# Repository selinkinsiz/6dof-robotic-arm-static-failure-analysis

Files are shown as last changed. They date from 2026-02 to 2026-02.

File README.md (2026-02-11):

# 6dof-robotic-arm-static-failure-analysis
Static structural analysis of a 6-DOF robotic arm using SolidWorks

## Project Overview
This project involves the mechanical design and static structural analysis of a 6-degree-of-freedom (6-DOF) robotic arm using SolidWorks Simulation. The objective was to evaluate structural integrity under applied loading conditions.

## Analysis Setup
- Material properties defined within SolidWorks
- Fixed support boundary condition applied at the base
- External load equivalent to 50 kg (~490 N) applied at the end-effector
- Finite Element Analysis (FEA) performed
- Von Mises stress criterion used for failure evaluation

## Evaluation Parameters
- Maximum von Mises stress distribution
- Maximum displacement and deformation
- Factor of Safety (FOS)
- Stress concentration regions

## Results
The analysis identified critical stress regions near joint connections and load-bearing sections. 
Maximum displacement was evaluated to ensure functional rigidity. 
Factor of Safety was calculated to verify structural reliability under the applied load.

## Tools Used
- SolidWorks
- SolidWorks Simulation (FEA Module)

## Repository Structure
- cad/ → CAD assembly and part files
- analysis/ → Simulation-related files and animation
- images/ → Stress, displacement, and FOS visualizations
- report/ → Detailed technical report
- presentation/ → Project presentation

## Conclusion
This project provided hands-on experience in finite element analysis, mechanical design validation, load application, and structural optimization for robotic systems.

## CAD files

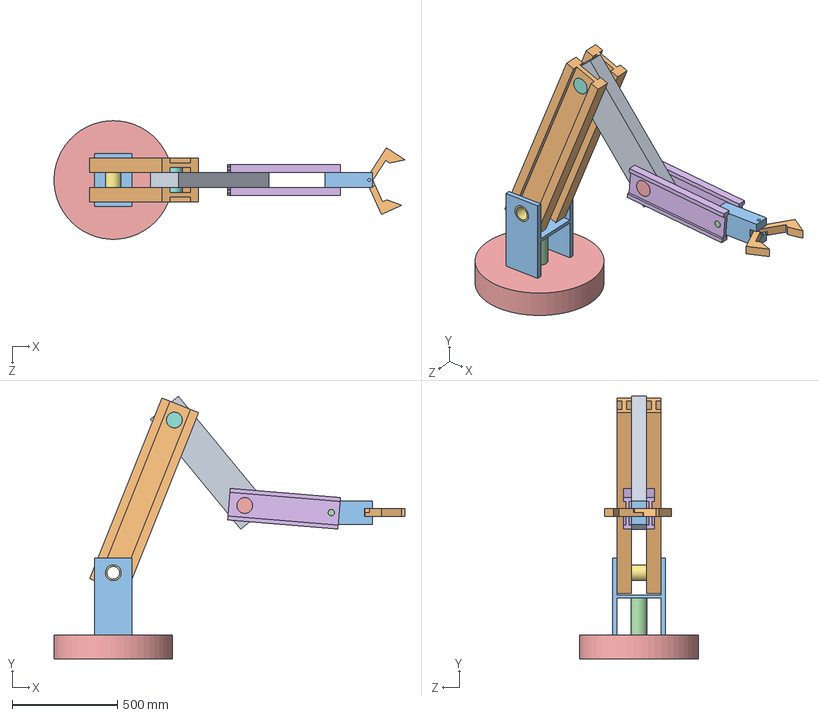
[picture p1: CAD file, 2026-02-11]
SOLIDWORKS Design Files/MECA_321_Project.SLDASM
1663.9 x 1244.5 x 562.5 mm
Base
Arm_1 x 2
Arm_2
Pin_1.2
Pin_Hole
Arm_3 x 2
Pin_2.3
Pin_3.4
Arm_4
Gripper x 2
Pin_Gripper

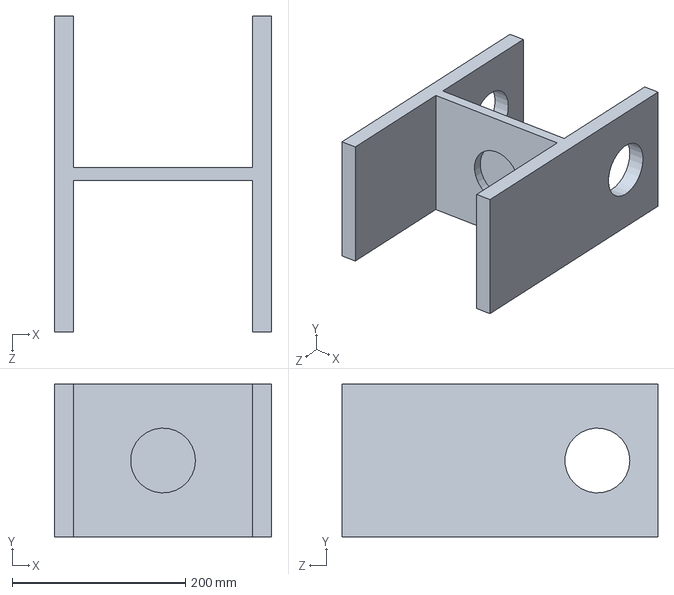
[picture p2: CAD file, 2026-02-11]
SOLIDWORKS Design Files/Body.SLDPRT
251.2 x 176.2 x 365.1 mm

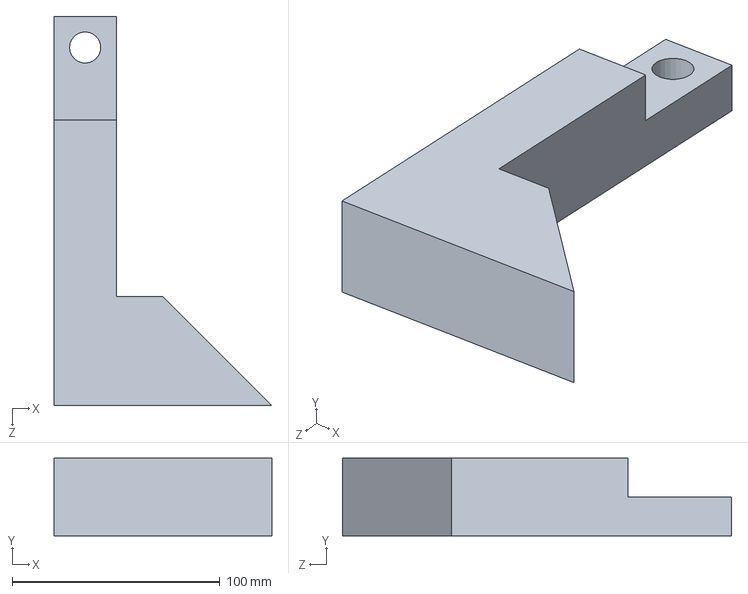
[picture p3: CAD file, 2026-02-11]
SOLIDWORKS Design Files/Gripper.SLDPRT
105.0 x 37.5 x 187.5 mm

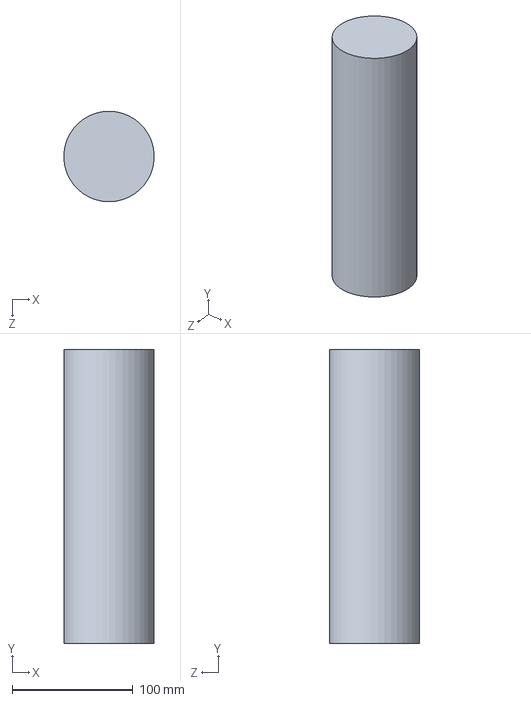
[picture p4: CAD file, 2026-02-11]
SOLIDWORKS Design Files/Cylinder.SLDPRT
74.8 x 243.8 x 75.0 mm

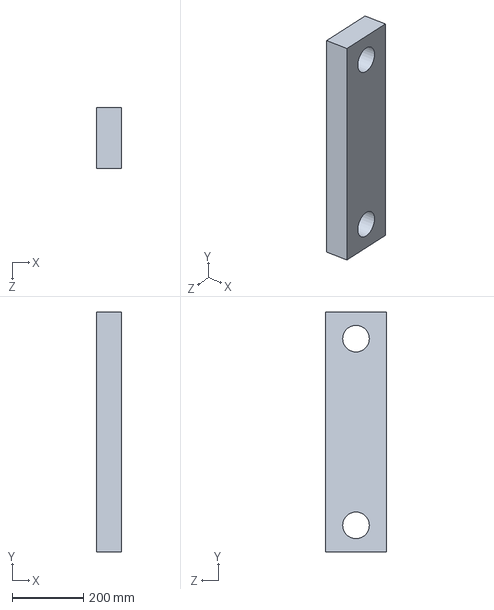
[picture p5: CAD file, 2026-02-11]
SOLIDWORKS Design Files/Arm_2.SLDPRT
71.2 x 674.7 x 172.5 mm

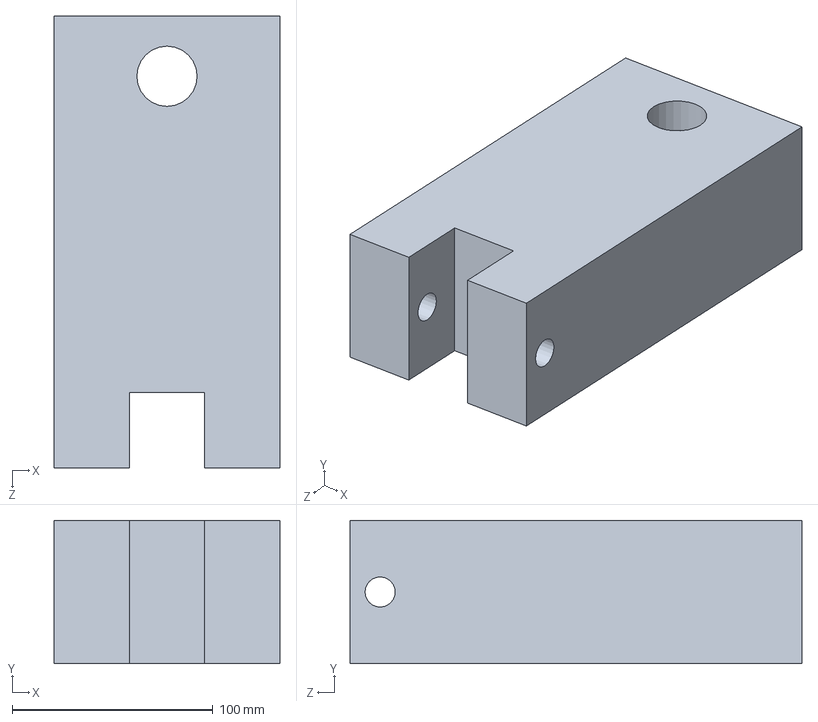
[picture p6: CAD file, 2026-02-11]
SOLIDWORKS Design Files/Arm_4.SLDPRT
112.5 x 71.2 x 225.0 mm

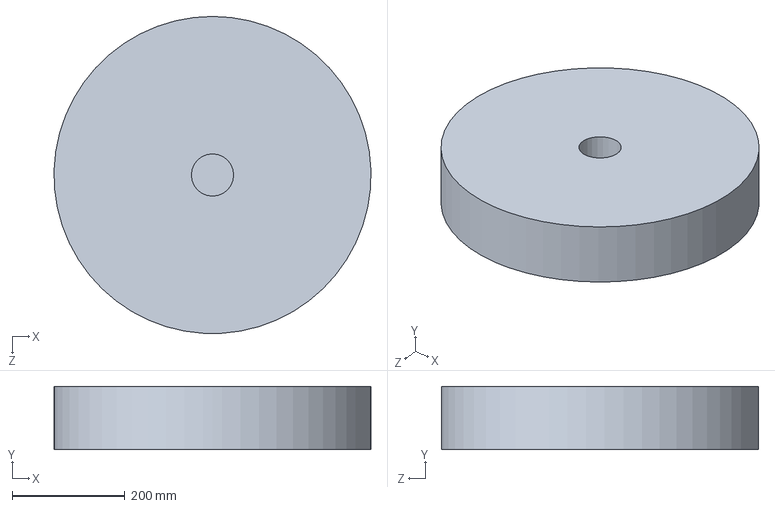
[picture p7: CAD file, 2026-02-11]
SOLIDWORKS Design Files/Base.SLDPRT
562.3 x 112.5 x 562.5 mm

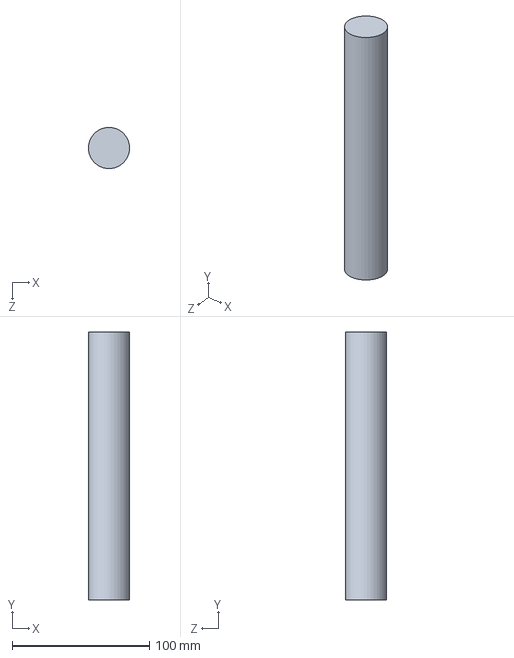
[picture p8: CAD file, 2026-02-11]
SOLIDWORKS Design Files/40_260pim.SLDPRT
30.0 x 195.0 x 30.0 mm

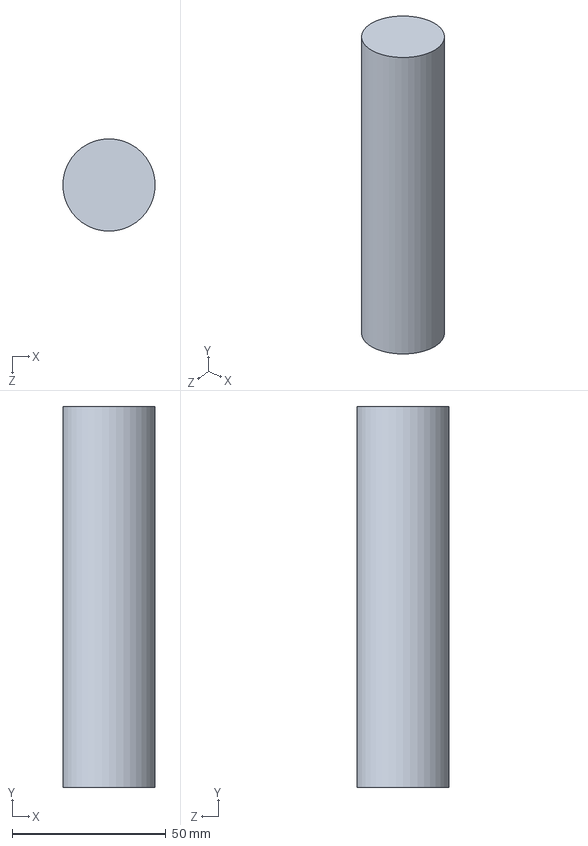
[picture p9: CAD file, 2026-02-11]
SOLIDWORKS Design Files/Pin_3.4.SLDPRT
30.0 x 123.7 x 30.0 mm

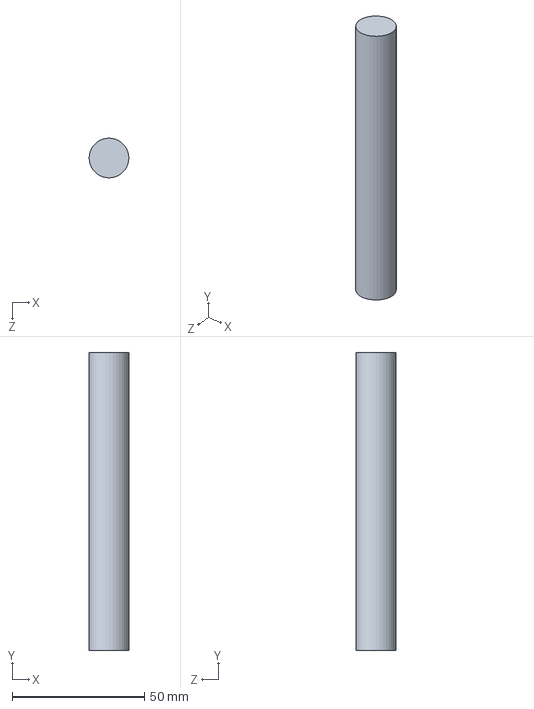
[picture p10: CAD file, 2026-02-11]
SOLIDWORKS Design Files/Pin_Gripper.SLDPRT
15.0 x 112.5 x 15.0 mm

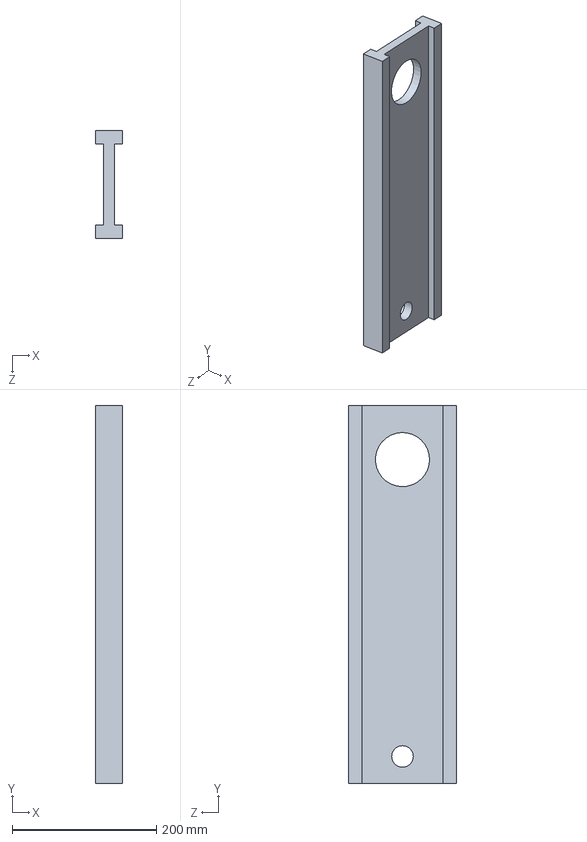
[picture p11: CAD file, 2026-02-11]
SOLIDWORKS Design Files/Arm_3.SLDPRT
37.5 x 524.3 x 150.0 mm

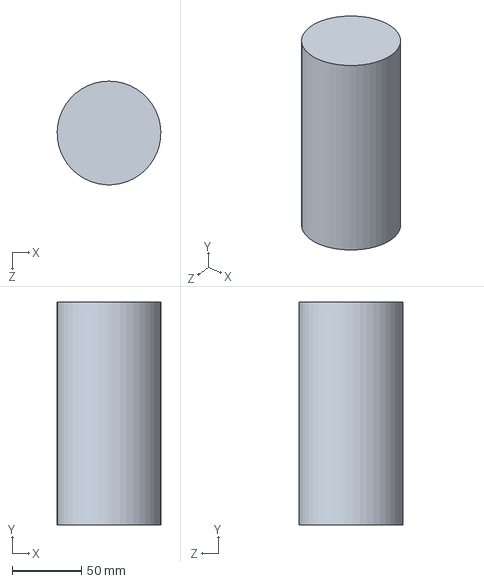
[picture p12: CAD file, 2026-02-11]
SOLIDWORKS Design Files/Pin_1.2.SLDPRT
75.0 x 161.2 x 75.0 mm

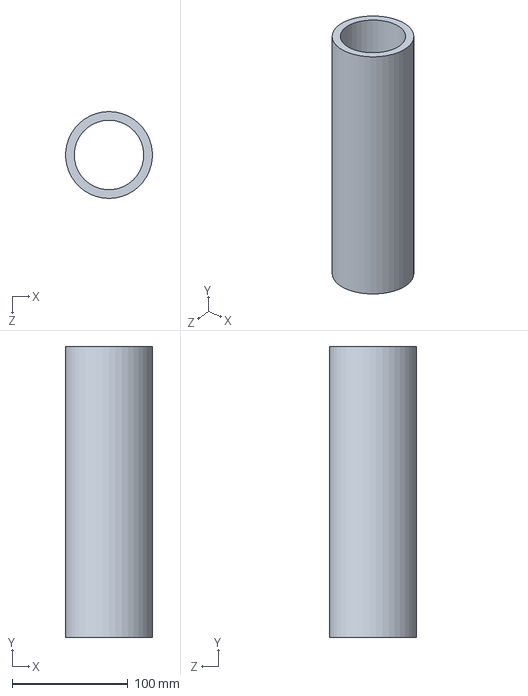
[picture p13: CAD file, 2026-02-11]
SOLIDWORKS Design Files/Pin_Hole.SLDPRT
74.8 x 251.2 x 75.0 mm

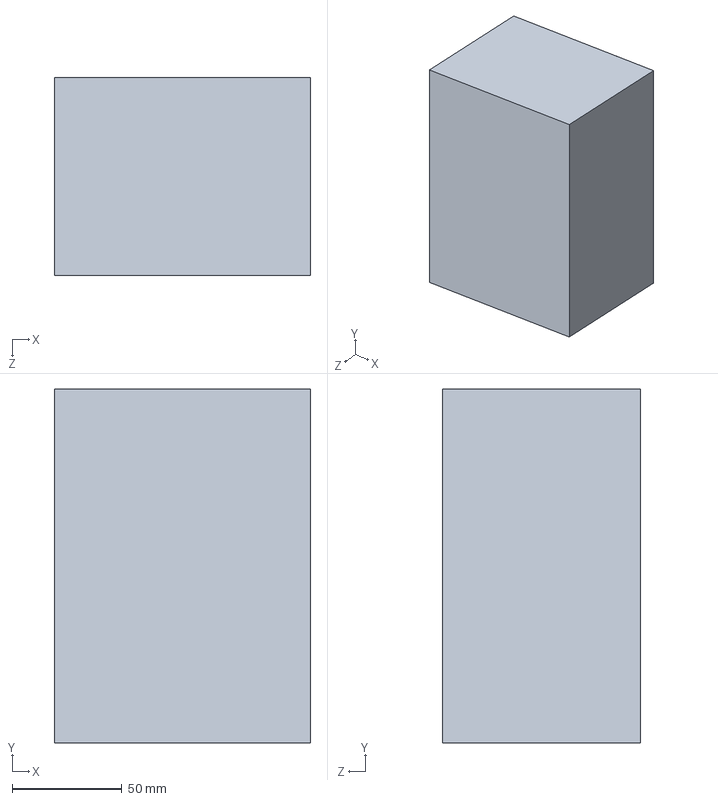
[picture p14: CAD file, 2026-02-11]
SOLIDWORKS Design Files/cube.SLDPRT
116.7 x 161.2 x 90.0 mm

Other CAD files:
SOLIDWORKS Design Files/Pin_2.3.SLDPRT
SOLIDWORKS Design Files/stick.SLDPRT
SOLIDWORKS Design Files/Arm_1.SLDPRT

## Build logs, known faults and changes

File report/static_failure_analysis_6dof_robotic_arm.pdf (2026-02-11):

Selin Rabia Kinsiz 122207037

Serra Lal Tosun 123207041

Yağız Gelen 122207048

Emir Eren 122207095

A Report Submitted to the

Mechatronics Engineering Department of

In MECA 321 Mechanics of Material

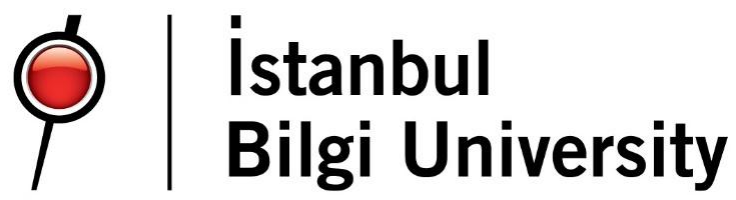
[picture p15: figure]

Table of Contents

### 1. Design Requirements and Assumptions

### 1.1 Design Requirements

- Payload Capacity: The robotic arm is designed to lift a payload of 50 kg located 2
meters | away | from | its | base.
- Safety Standards: A minimum Factor of Safety (FOS) of 2 is targeted for all structural
components | to | prevent | static | failure.
- Structural Geometry: Industrial standard profiles (I beams) are utilized for the arm links to optimize the strength to weight ratio and ensure manufacturability.
- Component Assembly: The design incorporates a combination of solid and hollow cylindrical pins of varying dimensions for joint assemblies, selected to optimize weight and structural integration.

### 1.2 Assumptions

- Material Properties: The material (HDPE) is assumed to be isotropic and homogeneous. Constant properties (Elastic Modulus: 1.07 GPa, Yield Strength: 22 MPa) are applied throughout the volume.
- Geometric Profile: The arm links are modeled using standard industrial I beam profiles to optimize the strength to weight ratio, in accordance with the design requirements.
- Static Loading: The payload of 50 kg is applied as a static force. Dynamic effects such as angular acceleration, inertia forces during movement, and vibrations are not included.

Boundary Conditions: The base of the robot is fixed at the bottom face, assuming a perfectly rigid installation surface with zero degrees of freedom.

Linear Elasticity: The analysis assumes linear elastic material behavior. Nonlinear effects such as plasticity, time dependent deformation, or large displacement non linearities are neglected for this static study.

Thermal Conditions: The analysis is conducted at standard room temperature (approx. 20-25°C). Thermal expansion or softening of the HDPE material is not considered.

### 2. Conceptual Design

The proposed robotic arm is designed as a multi segment serial manipulator. Specifically engineered to lift a 50 kg payload at a maximum reach of 2 meters. The design balances structural strength and weight efficiency. It utilizes a step-down linkage strategy to minimize the moment of inertia and stress on the base joints.

### 2.1 Configuration and Degrees of Freedom (DOF)

The robotic arm consists of a series of rigid links connected by rotational joints. The configuration is arranged to provide the necessary workspace and control for the lifting task. The design features the following primary segments:

- Base & Body: Provides a rigid foundation and vertical difference.
- Serial Linkages: The arm utilizes a successive arrangement of links that decrease in size and mass from the shoulder to the end effector. This configuration allows for a fully extended "worst case" reach while maintaining stability.

### 2.2 Structural Optimization and Material

To satisfy the design requirements, the arm links are designed with standard I beam profiles

- Mass Distribution Strategy: As seen in the design data, the mass of the links is progressively reduced (from approx. 13.5 kg for the first link to 1.5 kg for the final link). This " decreasing" strategy significantly reduces the bending moment applied to the root joints and optimizes the center of mass location.
- Material: High Density Polyethylene (HDPE) is selected as the primary structural material (E = 1.07 GPa), offering a high strength to weight ratio crucial for this multi-link setup.

### 2.3 Assembly and Joint Design

The mechanical integration of the segments is achieved using a specifically calculated pin system.

- Pin Selection: The assembly incorporates a hybrid approach using both solid pins and a hollow pin.
- Function: Hollow pins are utilized in lower stress joints to further reduce the total weight, while solid pins are kept for critical load bearing joints, ensuring the design meets the safety factor requirements.

### 3. CAD Design (SolidWorks)

The complete 3D geometric model of the robotic arm was developed using SolidWorks software, sticking to the project requirements for solid modeling and parametric design.

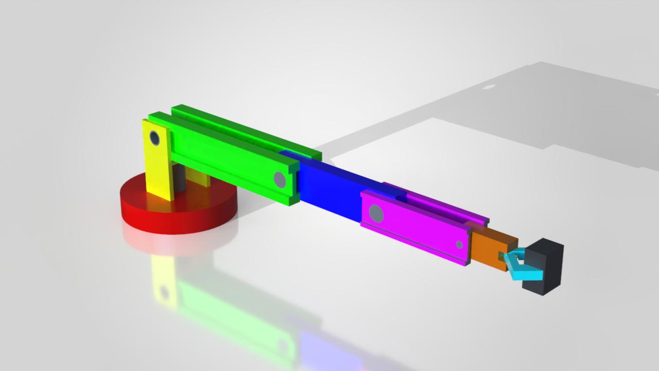
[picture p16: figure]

### 3.1 Modeling Methodology

The design process began with the creation of individual components representing the base, vertical body, and the four arm segments.

- Part Creation: Each link was modeled by sketching the cross-sectional profiles and using extrusion features to generate the 3D geometry. As specified in the conceptual design, the links were shaped to resemble I beam profiles to optimize rigidity.
- Pin & Connection Modeling: Specific connection pins were modeled as separate components. A combination of solid and hollow cylindrical pins was created to accurately represent the physical assembly and mass distribution.

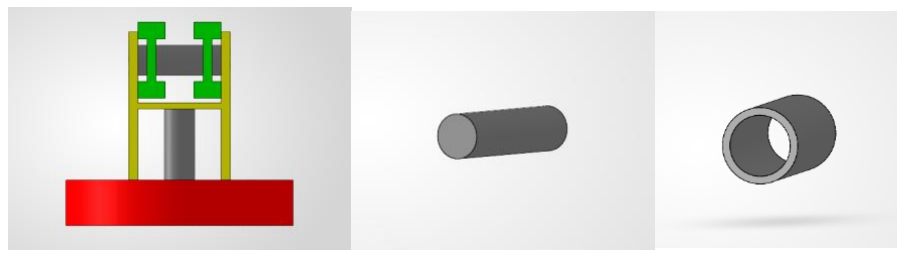
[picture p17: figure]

### 3.2 Assembly and Constraints

The individual parts were integrated into a final assembly file (.SLDASM) using standard mating conditions.

- Joint Constraints: Centered and aligned mates were applied between the link holes and the connecting pins to define the proper alignment of the revolute joints.
- Configuration: For the design validation, the assembly was constrained in a fully extended horizontal position. This configuration represents the "worst case" scenario where the moment arm is longest (2 meters), ensuring that following analyses cover the most critical loading condition.

### 3.3 Material Assignment and Mass Properties

To ensure accurate physical simulation, the material properties of High-Density Polyethylene (HDPE) were assigned to all structural components within the SolidWorks environment.

- Mass Calculation: Using the "Mass Properties" tool, the weight of each component and the center of gravity (COG) of the entire assembly were calculated. The payload was modeled by main the mass properties of the end effector load to 50 kg, simulating the target lifting capacity.

### 4. Material and Cross-Section Selection

This section outlines the reason behind the selection of materials and geometric profiles used in the robotic arm. The choices were driven by the design objectives of minimizing weight while ensuring sufficient stiffness to support the 50 kg payload.

Table 1: Material properties assigned to the robotic arm components

Component | Material | E (GPa) | Yield Strength (MPa) | Density (kg/m³)
Base | High-Density Polyethylene | 1.07 | 22 | 960
Body | High-Density Polyethylene | 1.07 | 22 | 960
Arm_1 | High-Density Polyethylene | 1.07 | 22 | 960
Arm_2 | High-Density Polyethylene | 1.07 | 22 | 960
Arm_3 | High-Density Polyethylene | 1.07 | 22 | 960
Arm_4 | High-Density Polyethylene | 1.07 | 22 | 960
Gripper | High-Density Polyethylene | 1.07 | 22 | 960

Cylinder | High-Density Polyethylene | 1.07 | 22 | 960
Pim_Hole | High-Density Polyethylene | 1.07 | 22 | 960
Pim_1.2 | High-Density Polyethylene | 1.07 | 22 | 960
Pim_2.3 | High-Density Polyethylene | 1.07 | 22 | 960
Pim_3.4 | High-Density Polyethylene | 1.07 | 22 | 960
Pim_Gripper | High-Density Polyethylene | 1.07 | 22 | 960

### 4.1 Cross-Section Selection: Industrial I-Beams

In accordance with the design requirements to use industrial standard profiles, the arm links are modeled with I beam cross-sections.

- Geometric Advantage: The I beam geometry places most of the material mass (flanges) away from the neutral axis. This significantly increases the Area Moment of Inertia (I) relative to the cross-sectional area.
- Bending Resistance: Since the primary failure mode for the horizontal arm is bending due to the vertical payload, the high moment of inertia provided by the I beam profile offers higher resistance to deflection compared to solid rectangular bars of equal weight.

### 5. Structural Analysis for Static Failure

In this section, the structural behavior of the robotic arm under static loading is evaluated. By applying the design loads to the HDPE structure, both analytical and numerical methods were used to calculate maximum stress and deflection. The results presented below demonstrate the comparison between theoretical expectations and simulation outputs, ensuring the design meets the minimum Factor of Safety criteria.

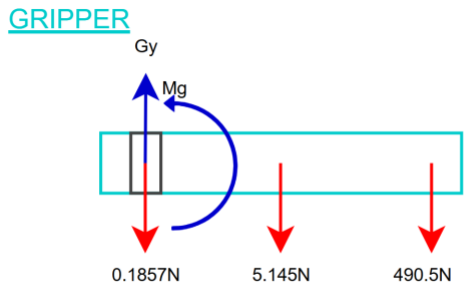
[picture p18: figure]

### 5.1 FBD

Gripper

CW = −

CCW = +

∑Fy = 0 , Gy = +495.837

∑MG = 0, MG = 0.46 + 72.834

MG = +73.294Nm

Arm4

A4y= +511.960N

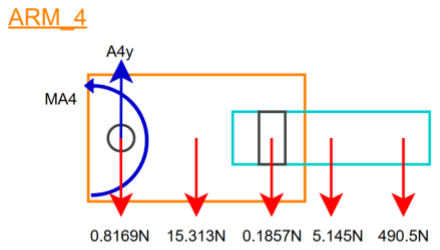
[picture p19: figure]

MA4= (15.313 × 0.07852) + (5.145 × 0.151792) + (490 × 0.328119) + (0.1857 × 0.18)

MA4= 1.202 + 0.781 + 161.124 + 0.033

MA4= 163.140Nm

Arm3

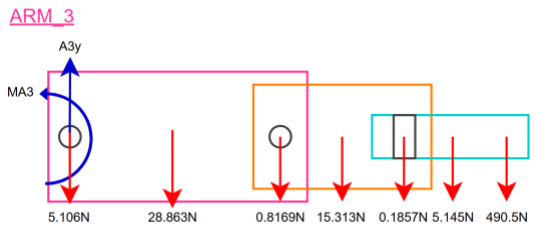
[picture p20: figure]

A3y= 510.958 + 28.853

A3y= 545.9396N

MA3= (0.19365 × 28.863) + (0.49035 × 15.313) + (0.68122 × 5.145) + (0.74032 ×
490.5) + (0.1857 × 0.59183) + (0.8169 × 0.41183)

MA3= 5.589 + 7.509 + 3.505 + 363.127 + 0.1099 + 0.3364

MA3= 380.176Nm

Arm2

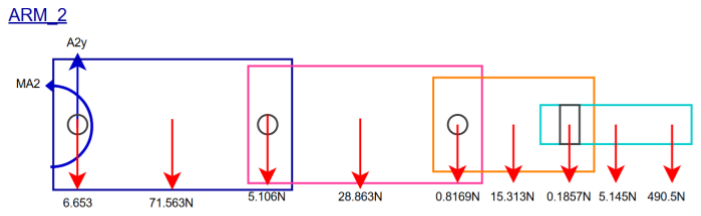
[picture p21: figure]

A2y= 539.821 + 71.563

A2y= 624.1456N

MA2= 18.774 + 20.733 + 15.543 + 6.204 + 620.483 + 0.207 + 0.765 + 2.6789

MA2= 685.3879Nm

Arm1

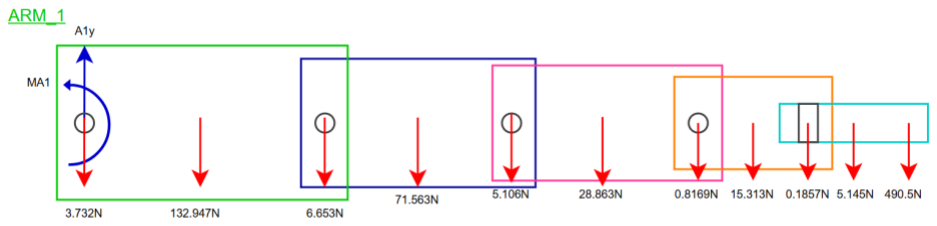
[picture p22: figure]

A1y= 611.384 + 132.947

A1y= 760.8244N

MA1= (0.39385 × 132.947) + (1.0234 × 71.563) + (1.49833 × 28,863) + (1.79503 × 15.313) + (1.9859 × 5.145) + (2.045 × 490.5) + (0.1857 × 1.89651) + (0.8169 × 1.71631) + (5.1058 × 1.30468) + (6.653 × 0.78)

MA1= 52.361 + 74.593 + 43.246 + 27.487 + 10.217 + 1003.073 + 0.33522 + 1.4022 + 6.6614 + 5.18934

MA1= 1224.582Nm

Body

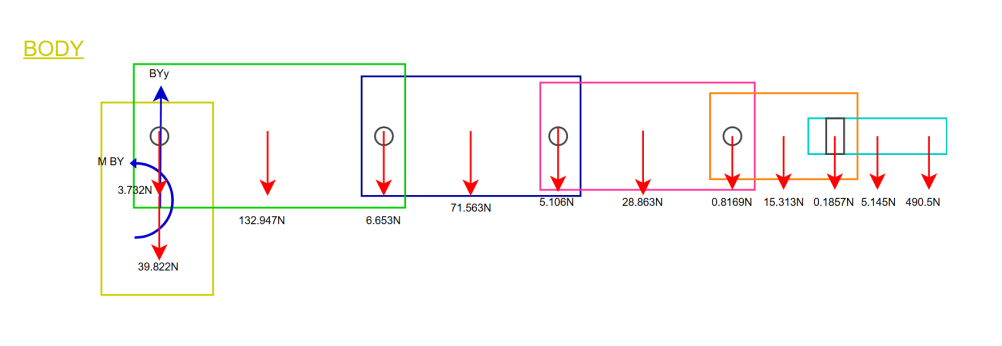
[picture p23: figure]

GBy= 760.8244 + 39.822

GBy= 800.6464N

MBB= 1224.582Nm , sent directly.

Base

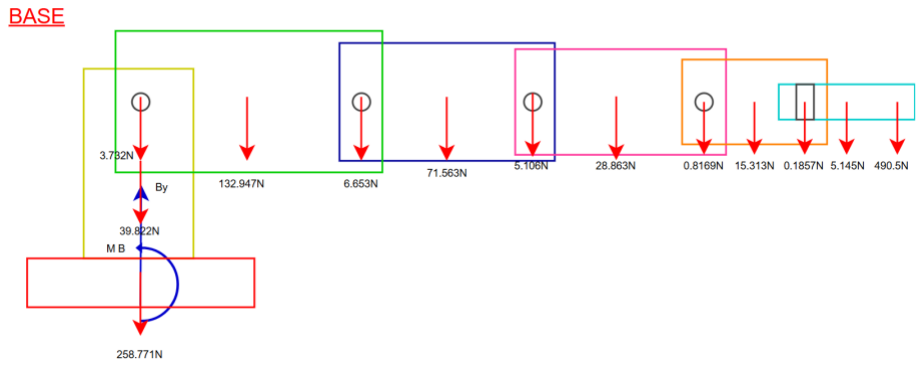
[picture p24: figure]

GBa= 760.8244 + 39.822 + 258.771

GBa= 1059.4174N

MBB= 1224.582Nm , sent directly.

### 5.2 V-M Diagrams

Section 1

∑Fx = 0

∑Fy = 0

∑Mg = 0

Mg = 490.5x

Mg = 28.989

x = 2.045 − 1.9855

x = 0.0591

Section 2

x = 2.045 − 1.79503

x = 0.24997

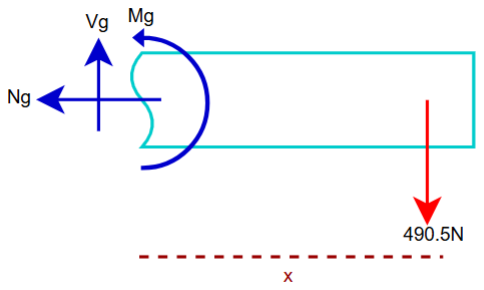
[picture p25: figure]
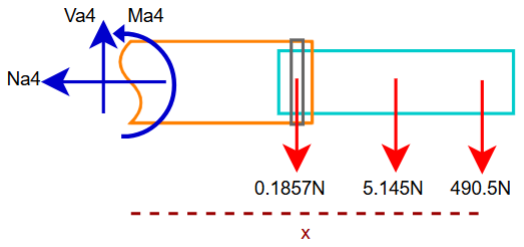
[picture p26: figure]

VA4 = 490.5 + 5.145 + 0.1857

VA4 = 495.8357N

MA4 = 490.5x + (5.145 × (x − 0.591)) + (0.1857 × (x − 0.14849))

MA4 = 495.8307x − 3.0683

MA4 = 120.875Nm

Section 3

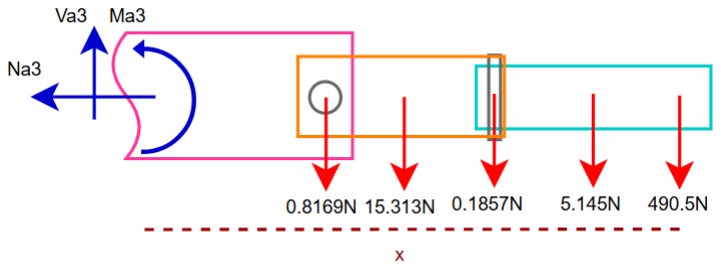
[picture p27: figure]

x = 2.045 − 1.4983

x = 0.5467

VA3 = 495.8307 + 15.313 + 0.8169

VA3 = 511.9606N

MA3 = 490.5x + (5.145 × (x − 0.591)) + (0.1857 × (x − 0.14849)) + (15.313 × (x − 0.24997)) + (0.8169 × (0.3285))

MA3 = 511.9606x − 7.1644

MA3 = 272.7245Nm

Section 4

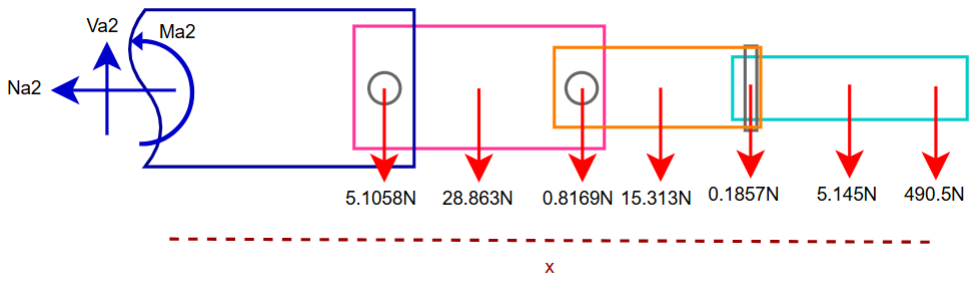
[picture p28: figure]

x = 2.045 − 1.04234

x = 1.00266

VA2 = 511.9606 + 28.863 + 5.1058

VA2 = 545.9294N

MA2 = 490.5x + (5.145 × (x − 0.591)) + (0.1857 × (x − 0.14849)) +
(15.313 × (x − 0.24997)) + (0.8169 × (x − 0.3285)) + (28.863 × (x − 0.5467)) + (5.1058 × (x − 0.74032))

MA2 = 545.9606x − 26.7237

MA2 = 520.689Nm

Section 5

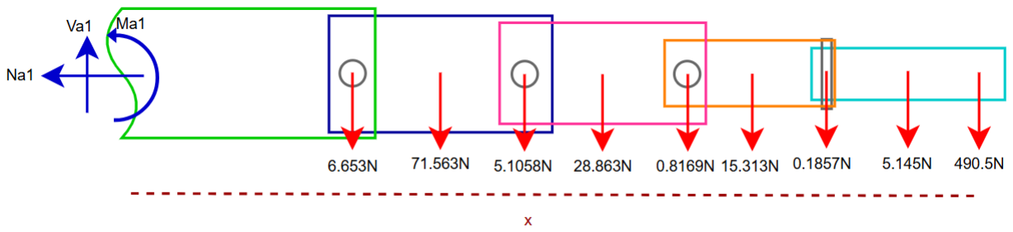
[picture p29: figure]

x = 2.045 − 0.39385

x = 1.65115

VA1 = 545.9294 + 71.563 + 6.653

VA1 = 624.1454N

MA1 = 624.1454x − 106.893

MA1 = 923.666Nm

Section 6

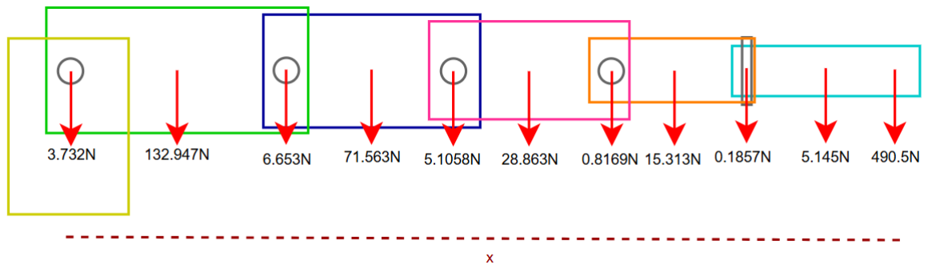
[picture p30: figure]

x = 2.045 − 0

x = 2.045

VBODY = 624.1454 + 132.947 + 3.732

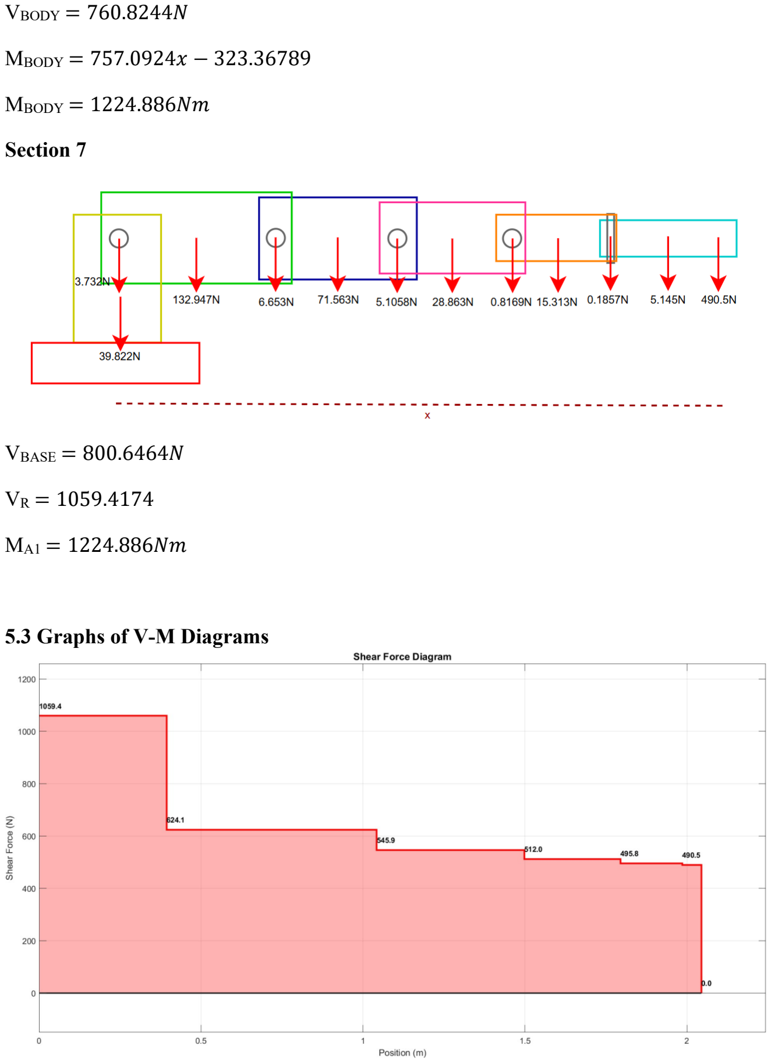
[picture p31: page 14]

VBODY = 760.8244N

MBODY = 757.0924x − 323.36789

MBODY = 1224.886Nm

Section 7

VBASE = 800.6464N

VR = 1059.4174

MA1 = 1224.886Nm

### 5.3 Graphs of V-M Diagrams

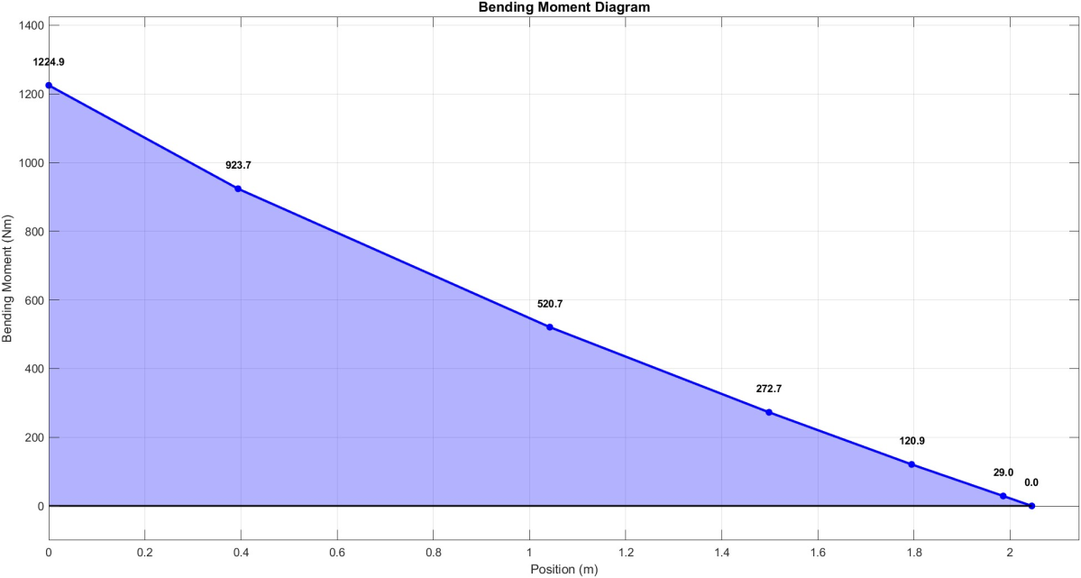
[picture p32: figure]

### 5.4 Bending Stress (σ = M · c / I)

Gripper

((28.989 × 0.01879))
(2 × 0.000267)

= 1.02 × 10³Pa

Arm4

(120.875 × 0.05625)
(0.002443)

= 2.783 × 10³Pa

Arm3

(272.7245 × 0.075)
(2 × 0.004006)

= 2.553 × 10³Pa

Arm2

(520.689 × 0.08625)
(0.022451)

= 2 × 10³Pa

Arm1

(923.666 × 0.09375)
(2 × 0.030621)

= 1.414 × 10³Pa

Body

(760.8244)
(0.01325359)

+

(1224.886 × 0.05625)
(0.554056)

= 5.753 × 10⁴Pa

Base

(800.6464)
(0.01234911)

+

(1224.886 × 0.28125)
(0.004914)

= 1.349 × 10⁵Pa

### 5.5 Pin Shear Stresses

Pin_3.4

511.9606
2 × 0.00070686 = 333.047kPa

Pin_2.3

545.9296
2 × 0.0044186 = 61.776kPa

Pin_1.2

624.1456
2 × 0.0044186 = 70.627kPa

Pin_Holes

760.8244
2 × 0.00159043 = 239.188kPa

Pin_Gripper

495.8307
2 × 0.00017671 = 1402.950kPa

### 5.6 Bearing Stresses

Pin_3.4

511.0606
0.03 × 0.12375 = 137901.8451Pa

Pin_2.3

545.9296
0.075 × 0.12375 = 58820.69764Pa

Pin_1.2

624.1456
0.075 × 0.16125 = 51608.9385Pa

Pin_Holes

760.8244
0.075 × 0.25125 = 40375.42421Pa

Pin_Gripper

495.8307
0.015 × 0.1125 = 293825.6Pa

### 5.7 Max Deflection ( δ = P · L³ / (3 · E · I) )

Gripper

(495.8307) × (0.14849)

3
(3) × (1.07 × 10⁹) × (0.000017)

= 2.97489 × 10⁻⁵ Meters

Arm4

(511.9606) × (0.18)

3
(3) × (1.07 × 10⁹) × (0.000002)

= 4.65070 × 10⁻⁴ Meters

Arm3

(545.9296) × (0. .41183)

3
(3) × (1.07 × 10⁹) × (0.000016)

= 7.42447 × 10⁻⁴ Meters

Arm2

(624.1456) × (0.52468)

3
(3) × (1.07 × 10⁹) × (0.000005)

= 5.61687 × 10⁻³ Meters

Arm1

(760.8244) × (0.78)

3
(3) × (1.07 × 10⁹) × (0.000065)

= 1.73041 × 10⁻³

Body

(1224.886) × (0.29505)

2
(2) × (1.07 × 10⁹) × (0.000183)

= 2.72281 × 10⁻⁴

Gripper Total Deflection = 8.8568 × 10⁻³

Arm4 Total Deflection = 8.8271 × 10⁻³

Arm3 Total Deflection = 8.3620 × 10⁻³

Arm2 Total Deflection = 7.6196 × 10⁻³

Arm1 Total Deflection = 2.0027 × 10⁻³

Body Total Deflection = 2.7228 × 10⁻⁴

### 5.8 Buckling Calculations ( Pcr = π² · E · I / (K · L)² )

Body

9.87 × (1.07 × 10⁹
) × (0.000021)
(2 × 0.3651)
2 | = 415.937kN

Cylinder

9.87 × (1.07 × 10⁹
) × (0.00002)
(1 × 0.24375)
2 | = 355.501kN

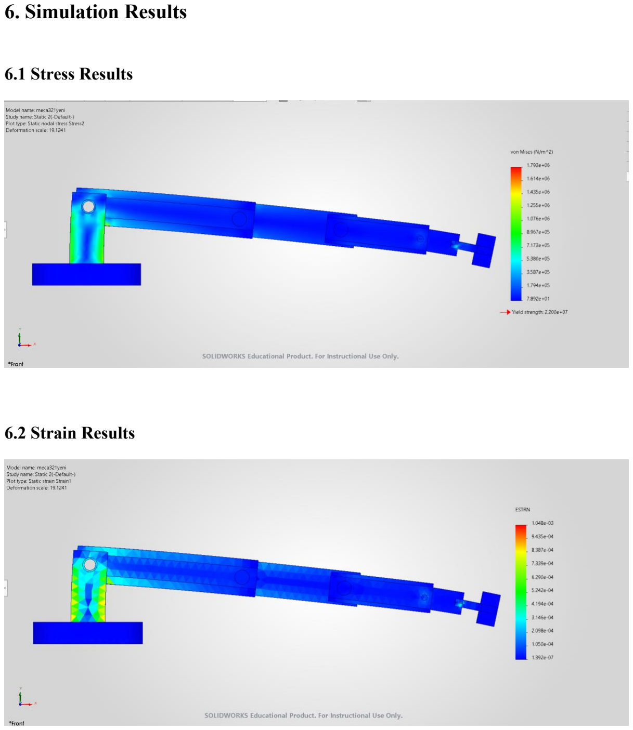
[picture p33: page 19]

### 6. Simulation Results

### 6.1 Stress Results

### 6.2 Strain Results

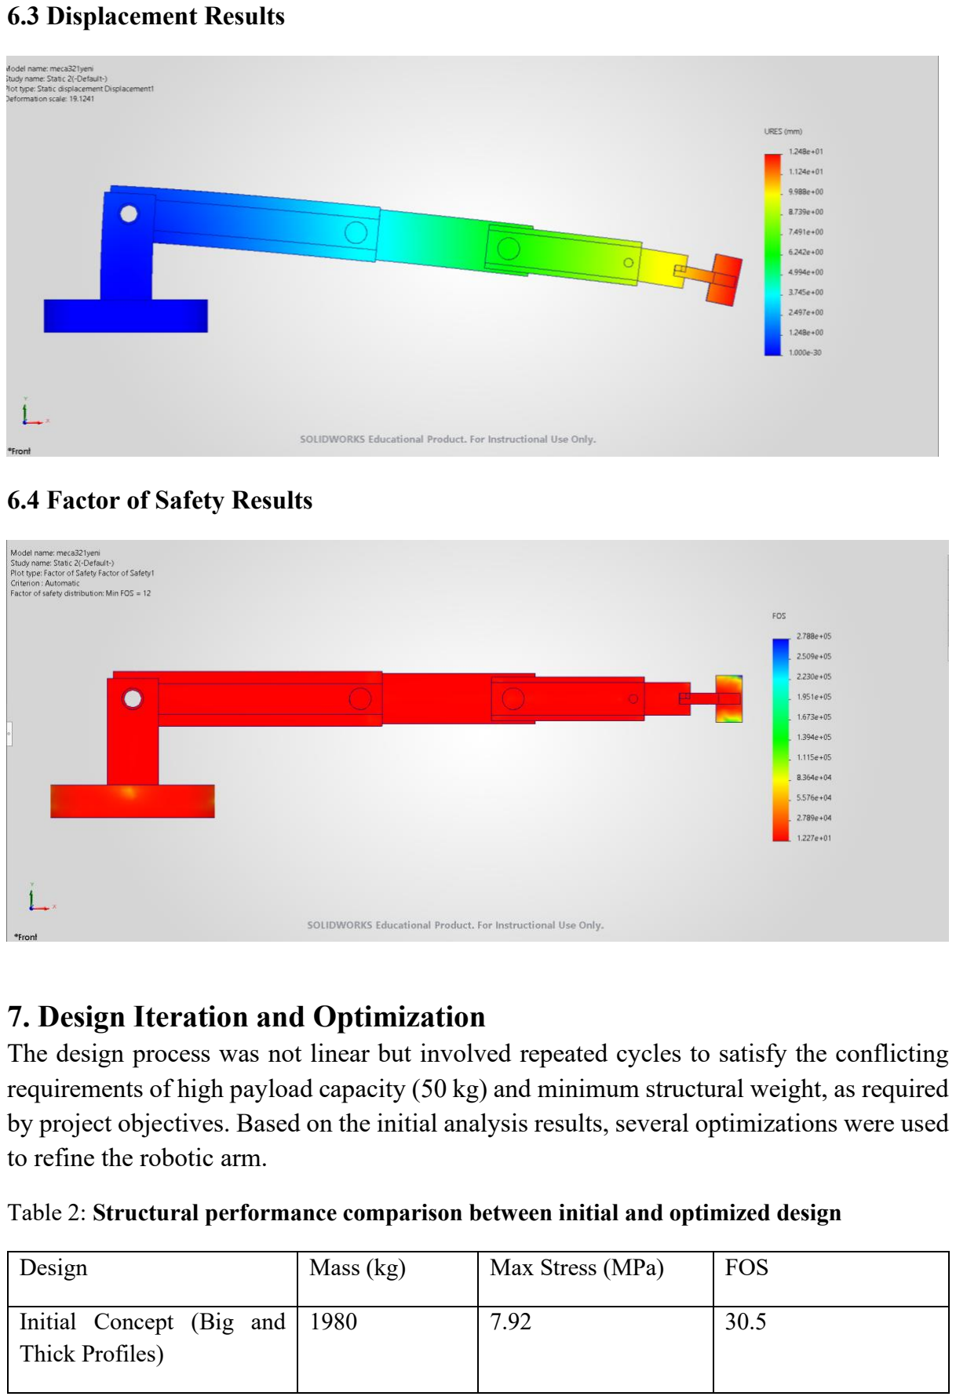
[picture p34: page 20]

### 6.3 Displacement Results

### 6.4 Factor of Safety Results

### 7. Design Iteration and Optimization

The design process was not linear but involved repeated cycles to satisfy the conflicting requirements of high payload capacity (50 kg) and minimum structural weight, as required by project objectives. Based on the initial analysis results, several optimizations were used to refine the robotic arm.

Table 2: Structural performance comparison between initial and optimized design

Design | Mass (kg) | Max Stress (MPa) | FOS
Initial Concept (Big and Thick Profiles) | 1980 | 7.92 | 30.5

Second Concept (Long Arms) | 352 | 1.89 | 15
Final Optimized Design (Tapered I-Beam) | 57.2 | 1.79 | 12.3

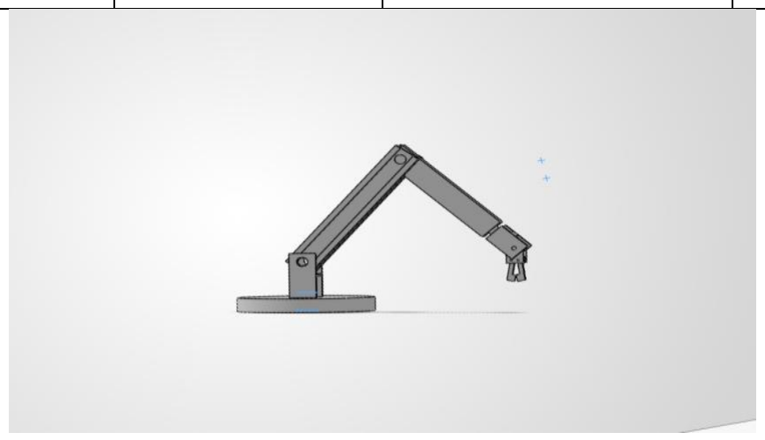
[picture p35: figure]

Initial Concept (Big and Thick Profiles)

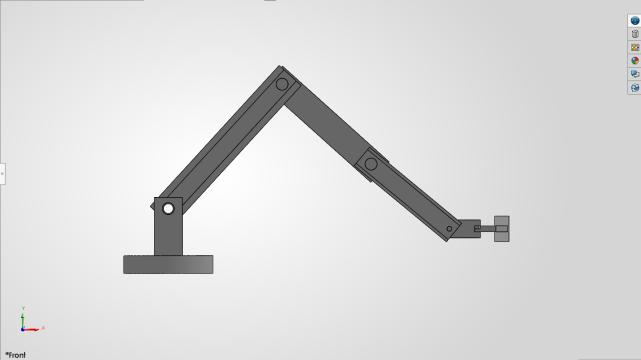
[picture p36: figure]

Second Concept (Long Arms)

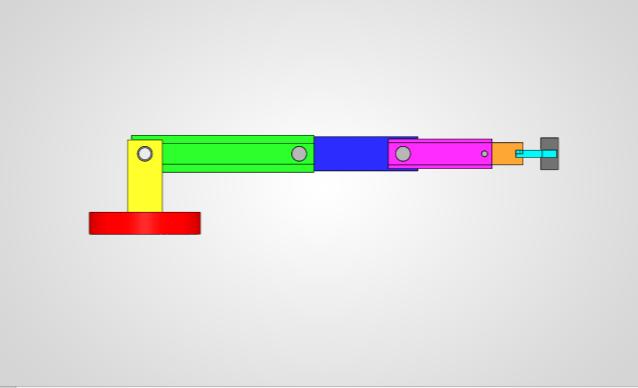
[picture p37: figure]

Final Optimized Design (Tapered I-Beam)

### 8. Cost Analysis

To evaluate the cost effectiveness of the design, an automated cost estimation was performed using the SolidWorks Costing module. Unlike simple raw material calculations, this analysis provides a detailed estimate that includes material costs, manufacturing operations (milling, drilling), and setup times for the HDPE components.

As shown in the SolidWorks generation report below (Figure 7.1 and Figure 7.2), the total estimated manufacturing cost for the robotic arm assembly is $ 620.90USD.

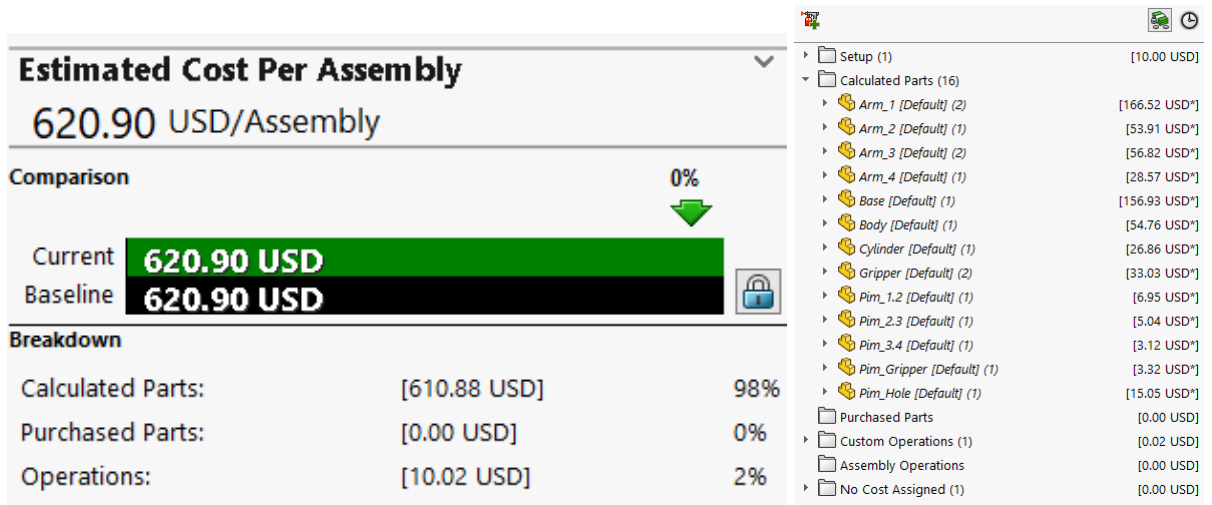
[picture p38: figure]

### 9. Distribution of Project Responsibilities

The specific contributions of each team member are outlined below:

- Emir Eren: Responsible for the design and simulation tasks. He created the 3D model in SolidWorks, ran the stress analysis tests (FEA), and prepared the motion animation video.
- Serra Lal Tosun & Yağız Gelen: Focused on calculations and the technical report. They checked the simulation results using manual formulas (Free Body Diagrams) and performed the cost analysis based on market prices. They also organized and wrote the final report details.
- Selin Rabia Kinsiz: Managed the presentation and supported the calculations. She helped the team with the mathematical verifications and summarized these analysis results to design a clear and effective presentation file.
- Collaborative Effort: Although everyone had specific tasks, the group worked together on every stage of the project. We brainstormed the initial design ideas, decided on the HDPE material, and solved the design problems together. Also, every group member reviewed and approved the final report and analysis results before submission.

### 10. Conclusions

The primary objective of this project was to design, analyze, and optimize an industrial robotic arm capable of manipulating a 50 kg payload at a maximum reach of 2 meters. Through a comprehensive engineering process involving geometric concept, material selection, and Finite Element Analysis (FEA), the design has been validated to meet and exceed all specified performance criteria.

The key findings and achievements of the study are summarized as follows:

- Compliance with Safety Standards: The structural analysis confirms that the arm is mechanically safe under the worst-case static loading scenario. The maximum Von Mises stress was recorded at 1.79 MPa, which is significantly lower than the Yield Strength of HDPE (22 MPa). Consequently, the design achieved a minimum Factor of Safety (FoS) of 12.3, higher than the project requirement of FoS > 2.
- Geometric Optimization and Weight Efficiency: By moving from initial solid blocks to tapered I beam profiles, the design successfully maximized the strength to weight ratio. This optimization strategy maintained the necessary rigidity while limiting the total structural mass to 57.2 kg, as a result reducing the inertial load on the base actuators.
- Stiffness and Serviceability: Despite the low elastic modulus of the selected polymer material (HDPE), the optimized geometry provided sufficient stiffness. The maximum deflection at the end effector was calculated as 12.48 mm. Given the significant arm span of 2 meters, this displacement is within acceptable limits for the intended material handling application.
- Economic and Manufacturing Feasibility: The cost estimation analysis performed via SolidWorks Costing indicates a total manufacturing cost of approximately $2,929.73 USD. This demonstrates that the proposed HDPE based design offers a cost-effective alternative to traditional metallic robotic arms without weakening structural integrity.

In conclusion, the proposed robotic arm design satisfies all design requirements regarding payload capacity, reach, safety, and cost-efficiency. The analytical results confirm that the system is structurally strong and ready for the detailed design or prototyping phase.

AI Usage Statement
AI tools were used only for grammar checking, figure formatting, and presentation structuring. Engineering analyses, and calculations were manually performed by us.

References
[1] Dassault Systemes, SolidWorks Simulation Documentation
[2] HDPE Material Datasheet, Typical Mechanical Properties.
[3] MECA 321 – Mechanics of Materials Lecture Notes
[4] Beer, F. P., Mechanics of Materials, 7th ed., McGraw Hill Education, 2015.
[5] Hibbeler, R. C., Mechanics of Materials, 9th ed., Prentice Hall, 2013.

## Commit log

2026-02-11 Rename PRESENTATION Static Failure Analysis of a 6 DOF Robotic Arm.pdf to presentation/static_failure_analysis_presentation.pptx
2026-02-11 Rename PRESENTATION Static Failure Analysis of a 6 DOF Robotic Arm.pdf to presentation/static_failure_analysis_presentation.pdf
2026-02-11 Rename presentation:Static Failure Analysis of a 6 DOF Robotic Arm.pdf to presentation/Static Failure Analysis of a 6 DOF Robotic Arm.pdf
2026-02-11 Rename Assembly Animation.mp4 to analysis/assembly_animation.mp4
2026-02-11 Rename presentation:Static Failure Analysis of a 6 DOF Robotic Arm.pdf to presentation/static_failure_analysis_presentation.pdf
